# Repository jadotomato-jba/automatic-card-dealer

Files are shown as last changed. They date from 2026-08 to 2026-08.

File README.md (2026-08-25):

# Automated Robotic Card Dealer
## Description
Simple robotic card dealer built off of a Raspberry Pi Zero 2 W and Arduino Nano. To deal cards, the stepper motor spins to move to different players, and a servo is used to flick a card from the bottom of the deck. Users select the number of cards and number of players on a display on the Pi.

## System Architecture
**Two Controllers:** Both a Raspberry Pi and Arduino Nano are used to divide labor between the two controllers. The Raspberry Pi handles higher level operations, including recieving user input and updating the live display. The Nano controls the actual movement of the two motors precisely and accurately.\
\
**Power Distribution:** All components are powered by a set of two battery backs in series that each hold 4 AA batteries for a total of 12V. One rail of the breadboard is used to supply 12V to the stepper motor, and a second rail supplies 5V to the Pi and Servo. A buck converter is used to step down from 12V to 5V. Finally, the Nano recieves power from the Pi via a Micro USB to USB-C data cable.\
\
**Communication Protocol:** Data is exchanged between the two controllers using UART protocol over the data cable. Each controller recieves confirmation that data was correctly recieved, and then that information is displayed on the Pi for the user to see.

## Tech Stack and Hardware Components
**Electronics**
+ Rasberry Pi Zero 2 W
+ Waveshare 1.44inch LCD HAT
+ Arduino Nano
+ LM2596 Step Down Module
+ Adafruit TMC2209 Stepper Motor Driver

**Motors**
+ NEMA 14 Bipolar Stepper Motor
+ SG90 Microservo

## Setup Guide
### Microcontroller Firmware
To flash the Arduino sketch, first clone the repository to your local machine. Then open the sketch in the Arduino IDE and plug in your Nano. In the tool menu, set the board and proccessor  to "Arduino Nano" and "ATmega328p (Old Bootloader)", respectively. Required libraries include the standard Arduino and Servo library, and the AccelStepper library by Michael McCauley. Download the AccelStepper library by opening the library menu, searching for AccelStepper, and downloading it. Finally, click the upload button to compile and upload the code to the Nano.

### Single-board Computer Software
Clone the repository to the Pi by opening the Raspberry pi terminal. Navigate to your home directory, and then clone the repositroy using `git clone https://github.com/jadotomato-jba/automatic-card-dealer.git` To set up the virtual environment for the Raspberry Pi, navigate to the software directory using `cd ~/automatic-card-dealer/software`. Create the virtual environment using `python3 -m venv venv`. Activate the environment by using `source venv/bin/activate`, and install dependencies by running `pip install -r requirements.txt`. Deactivate the environment using `deactivate`. 

### Service/Daemon Configuration
Copy `dealer_startup.service` to the system folder using `sudo cp ~/software/dealer_startup.service /etc/systemd/system/`. Reload the Systemd daemon with `sudo systemctl daemon-reload`. Enable the service on boot with `sudo systemctl1 enable dealer_startup.service`, and finally start the service imedietly using `sudo systemctl start dealer_startup.service`.

## Engineering Challenges

## Future Implementations
+ Custom PCB to upgrade from the breadboard
+ 3D printed housing to encase the entire device
+ Rechargeable batteries
+ Custom-built ejector arm for servo

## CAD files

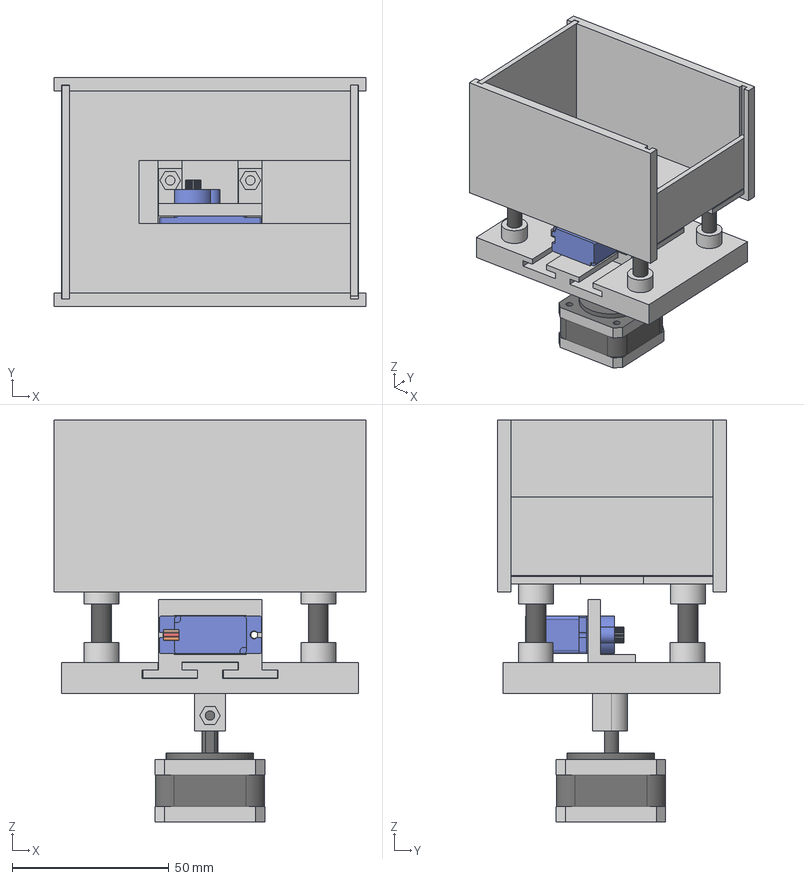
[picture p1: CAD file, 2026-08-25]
hardware/step/entire_motor_assembly.step
99.6 x 73.3 x 128.4 mm
Nema_14_PHB35Y20-404AD
SERVO_SG90

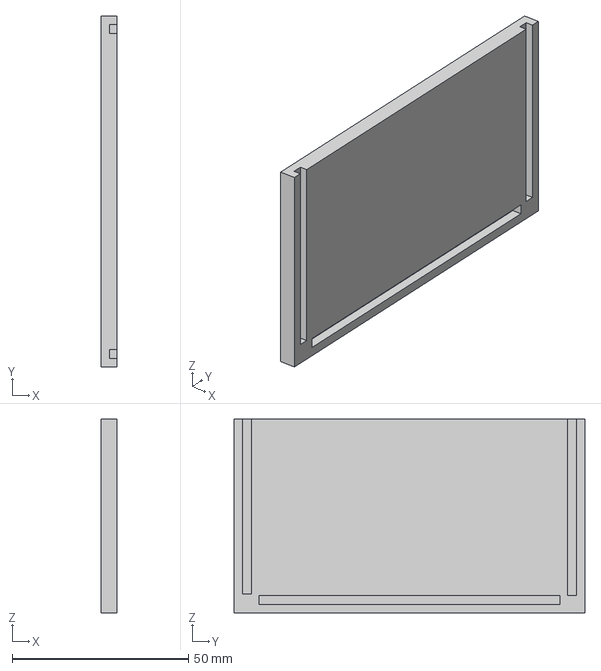
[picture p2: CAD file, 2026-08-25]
hardware/step/left_wall.step
4.40 x 99.6 x 55.0 mm

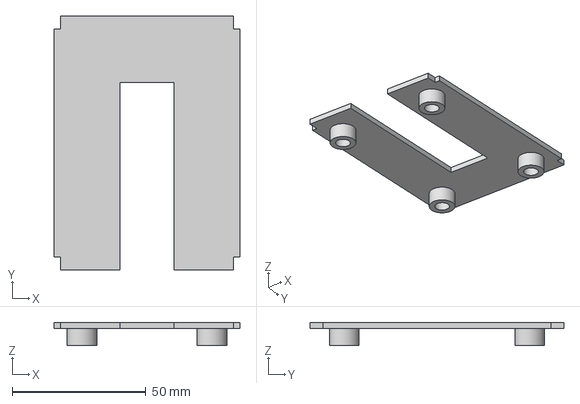
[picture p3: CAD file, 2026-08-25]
hardware/step/card_floor.step
69.3 x 94.8 x 8.75 mm

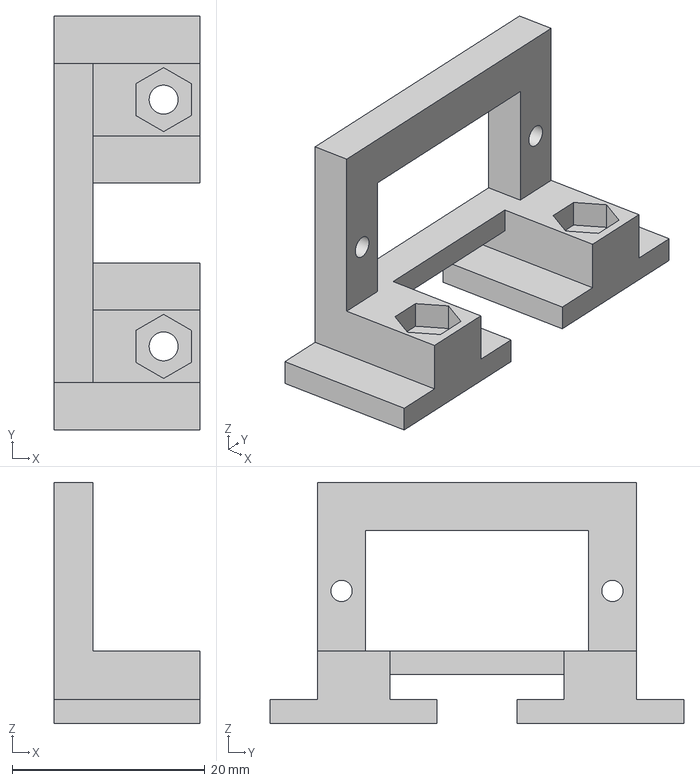
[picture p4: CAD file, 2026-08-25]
hardware/step/servo_bracket.step
15.1 x 42.9 x 25.0 mm

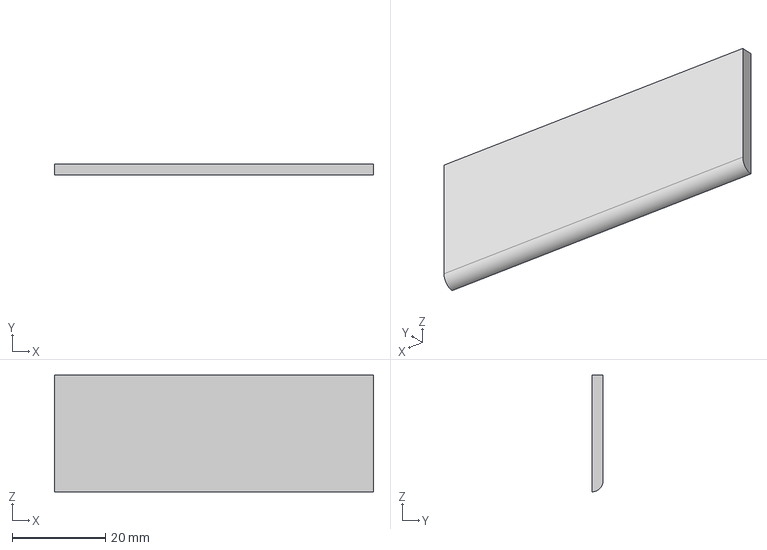
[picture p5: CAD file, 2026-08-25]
hardware/step/front_wall.step
68.3 x 2.40 x 25.0 mm

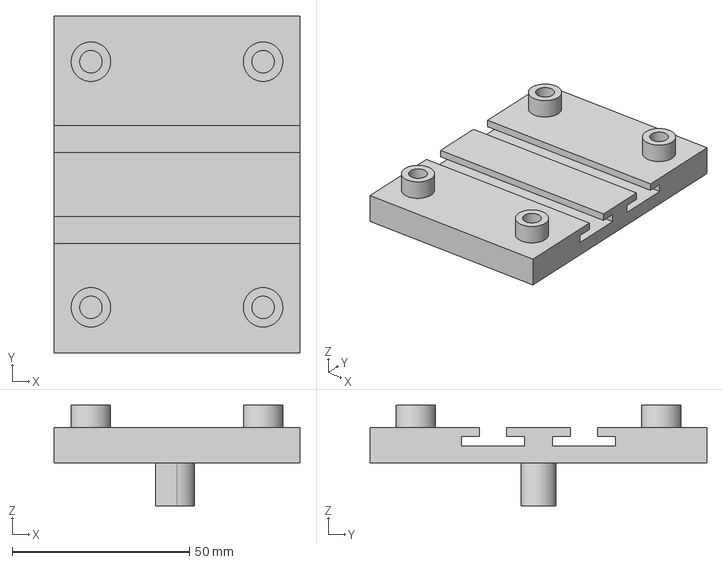
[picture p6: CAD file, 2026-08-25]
hardware/step/card_holder_base_to_stepper.step
69.3 x 94.8 x 28.4 mm

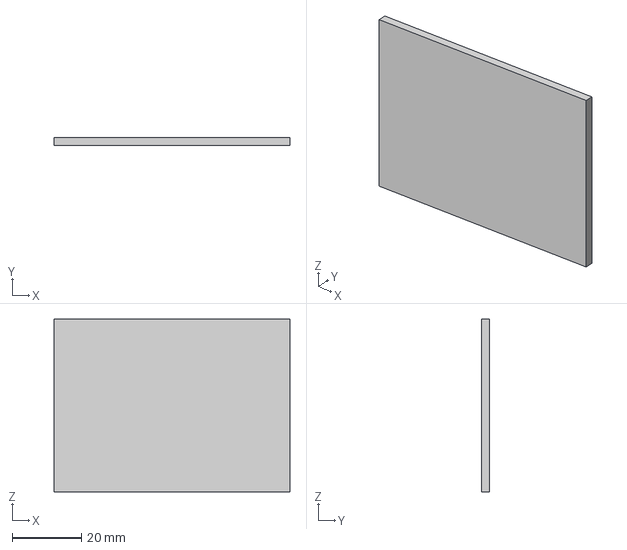
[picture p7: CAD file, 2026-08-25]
hardware/step/back_wall.step
68.3 x 2.40 x 50.0 mm

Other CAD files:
hardware/step/right_wall.step
hardware/stls/back_wall.stl
hardware/stls/card_floor.stl
hardware/stls/card_holder_base_to_stepper.stl
hardware/stls/entire_motor_assembly.stl
hardware/stls/front_wall.stl
hardware/stls/left_wall.stl
hardware/stls/right_wall.stl
hardware/stls/servo_bracket.stl

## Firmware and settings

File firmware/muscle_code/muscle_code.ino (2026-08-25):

#include "Arduino.h"
#include <Servo.h>
#include <AccelStepper.h>

// Servo stuff
#define SERVO_PIN 6
#define SERVO_UP_LIMIT 180
#define SERVO_DOWN_LIMIT 70
#define SERVO_START_ANGLE SERVO_UP_LIMIT
#define SERVO_END_ANGLE SERVO_DOWN_LIMIT
static Servo cardFlicker;

// Stepper things
#define DIR_PIN 3
#define STEP_PIN 4
#define STARTING_POSITION 0
#define MAX_STEP 1600
#define MAX_SPEED 2000
#define ACCELERATION 1500
AccelStepper dealerStepper(AccelStepper::DRIVER, STEP_PIN, DIR_PIN);

// Solid State Machine Things
#define DEALING 2
#define LISTENING 1
int state;
int players_to_deal;
int cards_to_deal;


void setup() {
  // put your setup code here, to run once:
  Serial.begin(9600);

  while (!Serial) { ; }

  cardFlicker.attach(SERVO_PIN);
  cardFlicker.write(SERVO_START_ANGLE);

  dealerStepper.setMaxSpeed(MAX_SPEED);
  dealerStepper.setAcceleration(ACCELERATION);
  dealerStepper.setCurrentPosition(STARTING_POSITION);

}

void loop() {
  // put your main code here, to run repeatedly:
  switch (state) {
    case LISTENING:
      if (Serial.available() > 0) {
        if (Serial.find("DEAL")) {
          state = DEALING;
        }
      }
      break;
    case DEALING: {
      players_to_deal = Serial.parseInt();
      cards_to_deal = Serial.parseInt();

      if (players_to_deal == 0 || cards_to_deal == 0) {
        state = LISTENING;
        break;
      }

      int result = deal_cards(players_to_deal,cards_to_deal);
      if (result) {
        Serial.println("STOPPED");
      } else {
        Serial.println("DEALT");
      }

      while (Serial.available() > 0) {Serial.read();}

      state = LISTENING;      
      break;
    }
    default:
      state = LISTENING;
      break;
  }
}

void flick_card() {
  cardFlicker.write(SERVO_END_ANGLE);
  delay(300);
  cardFlicker.write(SERVO_START_ANGLE);
  delay(300);
  return;
}

int deal_cards(int num_players, int num_cards) {
  int steps_between_players = MAX_STEP/num_players;
  int positions[12] = {0};
  for (int i = 1; i < num_players; i++) {
    positions[i] = positions[i-1] + steps_between_players;
  }
  for (int i = 0; i < num_cards; i++) {
    int result = deal_one_round(positions, num_players);
    if (result) {
      return result;
    }
    dealerStepper.moveTo(STARTING_POSITION);
    result = move_stepper();
    if (result) {
      return result;
    }
    dealerStepper.setCurrentPosition(STARTING_POSITION);
  }
  return 0;
}

int deal_one_round(int * positions, int num_players) {
  for(int player = 0; player < num_players; player++) {
    dealerStepper.moveTo(positions[player]);
    int result = move_stepper();
    if (result) {
      return result;
    }
    flick_card();
  }
  return 0;
}

int move_stepper() {
  static String incomingCommand = "";
  while (dealerStepper.distanceToGo() != 0) {
    dealerStepper.run();
    if (Serial.available() > 0) {
      char c = Serial.read();
      if (c == '\n' || c == '\r') {
        if (incomingCommand == "STOP") {
          incomingCommand = "";
          return 1;
        }
        incomingCommand = "";
      } else {
        incomingCommand += c;
      }
    }
  }
  return 0;
}

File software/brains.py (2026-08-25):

# Imports for screen
from luma.core.interface.serial import spi
from luma.lcd.device import st7735
from luma.core.render import canvas
from PIL import ImageFont

# Setting up GPIO
import RPi.GPIO as GPIO
GPIO.setmode(GPIO.BCM)

JOYSTICK_UP = 26
JOYSTICK_DOWN = 5
JOYSTICK_RIGHT = 19
JOYSTICK_LEFT = 6
JOYSTICK_CENTER = 13

GPIO.setup(JOYSTICK_UP, GPIO.IN, pull_up_down=GPIO.PUD_UP)
GPIO.setup(JOYSTICK_DOWN, GPIO.IN, pull_up_down=GPIO.PUD_UP)
GPIO.setup(JOYSTICK_RIGHT, GPIO.IN, pull_up_down=GPIO.PUD_UP)
GPIO.setup(JOYSTICK_LEFT, GPIO.IN, pull_up_down=GPIO.PUD_UP)
GPIO.setup(JOYSTICK_CENTER, GPIO.IN, pull_up_down=GPIO.PUD_UP)

import time

import serial


#States for selected items
DEAL_SELECTED = 0
PLAYERS_SELECTED = 1
CARDS_SELECTED = 2
MINIMUM_PLAYERS = 0
MAXIMUM_PLAYERS = 12
MINIMUM_CARDS = 0

#Color defintions
UNSELECTED_TEXT_COLOR = "black"
UNSELECTED_BACKGROUND = "white"
SELECTED_TEXT_COLOR = "white"
SELECTED_BACKGROUND = "#2626AB"


# Font sizes
TITLE_FONT_SIZE = 14
SUBTITLE_SIZE = 10
PRESS_TO_DEAL_SIZE = 12
UP_DOWN_SIZE = 30
NUMBER_FONT_SIZE = 20
MESSAGE_TEXT_SIZE = 12


def draw_menu(selected: int, players: int, cards: int):    
    with canvas(device) as draw:
        draw.rectangle([0,0,128,128], UNSELECTED_BACKGROUND)

        draw.text((64,10), "Card Dealer 3000", fill=UNSELECTED_TEXT_COLOR, anchor="mm", font_size=TITLE_FONT_SIZE)

        if players == 0:
            players = "OFF"
        
        if cards == 0:
            cards = "OFF"

        if selected == PLAYERS_SELECTED:
            draw.rectangle([5,18,59,110], fill=SELECTED_BACKGROUND)
            draw.text((32,25), "Players", fill=SELECTED_TEXT_COLOR, anchor="mm", font_size=SUBTITLE_SIZE)
            draw.text((32,40), "+", fill=SELECTED_TEXT_COLOR, anchor="mm", font_size=UP_DOWN_SIZE)
            draw.text((32,100), "-", fill=SELECTED_TEXT_COLOR, anchor="mm", font_size=UP_DOWN_SIZE)
            draw.text((32,70), str(players), fill=SELECTED_TEXT_COLOR, anchor="mm", font_size=NUMBER_FONT_SIZE)
        else:
            draw.text((32,25), "Players", fill=UNSELECTED_TEXT_COLOR, anchor="mm", font_size=SUBTITLE_SIZE)
            draw.text((32,40), "+", fill=UNSELECTED_TEXT_COLOR, anchor="mm", font_size=UP_DOWN_SIZE)
            draw.text((32,100), "-", fill=UNSELECTED_TEXT_COLOR, anchor="mm", font_size=UP_DOWN_SIZE)
            draw.text((32,70), str(players), fill=UNSELECTED_TEXT_COLOR, anchor="mm", font_size=NUMBER_FONT_SIZE)

        if selected == CARDS_SELECTED:
            draw.rectangle([69,18,123,110], fill=SELECTED_BACKGROUND)
            draw.text((96,25), "Cards", fill = SELECTED_TEXT_COLOR, anchor="mm", font_size=SUBTITLE_SIZE)
            draw.text((96,40),"+", fill=SELECTED_TEXT_COLOR, anchor="mm", font_size=UP_DOWN_SIZE)
            draw.text((96, 100), "-", fill=SELECTED_TEXT_COLOR, anchor="mm", font_size=UP_DOWN_SIZE)
            draw.text((96,70), str(cards), fill=SELECTED_TEXT_COLOR, anchor="mm", font_size=NUMBER_FONT_SIZE)
        else:
            draw.text((96,25), "Cards", fill = UNSELECTED_TEXT_COLOR, anchor="mm", font_size=SUBTITLE_SIZE)
            draw.text((96,40),"+", fill=UNSELECTED_TEXT_COLOR, anchor="mm", font_size=UP_DOWN_SIZE)
            draw.text((96, 100), "-", fill=UNSELECTED_TEXT_COLOR, anchor="mm", font_size=UP_DOWN_SIZE)
            draw.text((96,70), str(cards), fill=UNSELECTED_TEXT_COLOR, anchor="mm", font_size=NUMBER_FONT_SIZE)

        if selected == DEAL_SELECTED:
            draw.rectangle([1,113,126,127], fill=SELECTED_BACKGROUND)
            draw.text((64,120), "Press CENTER to deal", SELECTED_TEXT_COLOR, anchor="mm", font_size=PRESS_TO_DEAL_SIZE)
        else:
            draw.text((64,120), "Press CENTER to deal", UNSELECTED_TEXT_COLOR, anchor="mm", font_size=PRESS_TO_DEAL_SIZE)

def is_button_pushed(button: int):
    return GPIO.input(button) == GPIO.LOW

def send_deal_command(players: int, cards: int, port):
    message = f"DEAL: {players},{cards}\n"
    port.write(message.encode('utf-8'))
    print(f"Sent message ({message}) to arduino")

def draw_message(string: str):
    with canvas(device) as draw:
        draw.rectangle([0,0,128,128], fill=UNSELECTED_BACKGROUND)
        draw.multiline_text((64,64), string, fill="black", anchor="mm", font_size=MESSAGE_TEXT_SIZE)
            
def main():
    time.sleep(15)

    try: 
        global serial_spi, device, arduino
        serial_spi = spi(port=0, device=0, gpio_RST=27, gpio_DC=25, gpio_LIGHT=24)
        device = st7735(serial_spi, width=128,  height=128, bgr=True, h_offset=1, v_offset=2, rotate=1)
        arduino = serial.Serial(port="/dev/ttyUSB0",baudrate=9600, timeout=1)
        time.sleep(2)

        playerCount = MINIMUM_PLAYERS
        cardCount = MINIMUM_CARDS
        currSelect = PLAYERS_SELECTED
        draw_menu(currSelect, playerCount, cardCount)

        while True:
            if is_button_pushed(JOYSTICK_UP):
                print("Up")
                if currSelect == CARDS_SELECTED:
                    cardCount+=1
                elif currSelect == PLAYERS_SELECTED:
                    if playerCount == MAXIMUM_PLAYERS:
                        playerCount = MINIMUM_PLAYERS
                    else: 
                        playerCount += 1
                draw_menu(currSelect, playerCount, cardCount)

            if is_button_pushed(JOYSTICK_RIGHT):
                print("Right")
                if currSelect == PLAYERS_SELECTED:
                    currSelect = CARDS_SELECTED
                elif currSelect == CARDS_SELECTED:
                    currSelect = PLAYERS_SELECTED
                draw_menu(currSelect, playerCount, cardCount)

            if is_button_pushed(JOYSTICK_LEFT):
                print("Left")
                if currSelect == PLAYERS_SELECTED:
                    currSelect = CARDS_SELECTED
                elif currSelect == CARDS_SELECTED:
                    currSelect = PLAYERS_SELECTED
                draw_menu(currSelect, playerCount, cardCount)

            if is_button_pushed(JOYSTICK_DOWN):
                print("Down")
                if currSelect == CARDS_SELECTED:
                    if cardCount == MINIMUM_CARDS:
                        pass
                    else:
                        cardCount-=1
                elif currSelect == PLAYERS_SELECTED:
                    if playerCount == MINIMUM_PLAYERS:
                        playerCount = MAXIMUM_PLAYERS
                    else: 
                        playerCount -= 1
                draw_menu(currSelect, playerCount, cardCount)
                
            if is_button_pushed(JOYSTICK_CENTER):
                print("Center")

                #Check if should break
                if cardCount == 0 or playerCount == 0:
                    break
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
